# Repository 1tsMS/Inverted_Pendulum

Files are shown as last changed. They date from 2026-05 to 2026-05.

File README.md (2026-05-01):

# 🎯 Inverted Pendulum on Cart (ESP32)

A real-world implementation of the classic inverted pendulum control problem using an ESP32, dual-loop PID control, and a belt-driven linear cart system.

This project demonstrates **nonlinear system stabilization**, **real-time control**, and **embedded implementation of cascade PID control**.

---

## ⚙️ System Overview

The system consists of:

* A **cart moving on a linear rail**
* A **free-rotating pendulum mounted on the cart**
* Real-time feedback using **encoders**
* A **cascade PID controller** to stabilize the pendulum

---

## 🧠 Control Architecture

This project uses a **cascade (dual-loop) PID control system**:

### 🔹 Inner Loop (Fast)

* Controls **pendulum angle**
* Responsible for **balancing**

### 🔹 Outer Loop (Slow)

* Controls **cart position**
* Keeps the cart near the center

```
Position PID → Target Angle → Angle PID → Motor Control
```

---

## 🧰 Hardware Components

### 🔌 Controller

* ESP32 WROOM Development Board

### ⚡ Motor & Drive

* 775 DC Motor (12V, 3000 RPM, dual shaft)
* BTS7960 High Power Motor Driver
* GT2 Belt Drive System
* 16 Teeth Pulley

### 🛤️ Mechanical System

* MGN9H Linear Guide Rail (0.5m)
* Sliding carriage (cart platform)

### 📡 Sensors

#### Pendulum Angle

* 600 PPR Incremental Rotary Encoder
* Mounted directly at the pendulum pivot

#### Cart Position

* AS5600 Magnetic Encoder (I2C)
* Magnet mounted on motor shaft

---

## ⚡ Power System

* 12V, 10A DC Power Supply

---

## 📐 Mechanical Design

* Pendulum:

  * Length: 25 cm
  * Material: Steel rod
  * No additional mass attached

* Drive system:

  * GT2 belt-driven linear motion
  * Compact and lightweight cart design

---

## 🧪 Features

* Real-time encoder feedback
* Multi-turn position tracking using AS5600
* Cascade PID control
* Software safety limits (angle + position)
* Serial-based live PID tuning
* Smooth motor control with filtering

---

## 🧠 Key Concepts Demonstrated

* Inverted pendulum stabilization
* Cascade control systems
* Real-time embedded control (ESP32)
* Encoder signal processing
* Nonlinear dynamics control

---

## 🚀 Getting Started

### 1. Hardware Setup

* Assemble cart on linear rail
* Mount pendulum securely on encoder shaft
* Install GT2 belt and pulley system
* Ensure smooth, low-friction motion

### 2. Wiring

* Connect motor driver to ESP32 GPIO pins
* Connect encoders (quadrature + I2C)
* Ensure **common ground across all components**

---

### 3. Upload Code

* Use Arduino IDE / PlatformIO
* Select ESP32 board
* Upload main control code

---

### 4. Serial Control

| Command | Function |
| --- | --- |
| S | Start system |
| X | Stop system |
| P | Set angle Kp |
| I | Set angle Ki |
| D | Set angle Kd |
| p | Set position Kp |
| d | Set position Kd |

---

## 🎯 PID Tuning Strategy

### Step 1: Tune Angle PID (Inner Loop)

* Disable position control
* Increase Kp until response is fast
* Add Kd to reduce oscillations
* Add small Ki for bias correction

### Step 2: Tune Position PID (Outer Loop)

* Enable position loop
* Start with small Kp
* Add Kd to reduce overshoot

---

## ⚠️ Safety Features

* Automatic motor cutoff if:

  * Pendulum angle exceeds safe limit
  * Cart exceeds track limits

---

## 🔧 Current Status

* Hardware: ✅ Completed
* Encoder feedback: ✅ Working
* PID control: ⚠️ In progress (balancing loop tuned)

---

## 🔮 Future Improvements

* LQR control implementation
* Higher control loop frequency
* Improved motor control using hardware PWM
* Better mechanical damping and rigidity
* Data logging and visualization

---

## 📸 Media

..

---

## 📌 Applications

* Control systems learning
* Robotics and automation education
* Embedded systems development
* Portfolio demonstration project

---

## 🧠 Author Notes

This project focuses on bridging **theory and practical implementation** of control systems. It highlights real-world challenges such as noise, delays, friction, and actuator limitations.

---

## 📜 License

MIT License

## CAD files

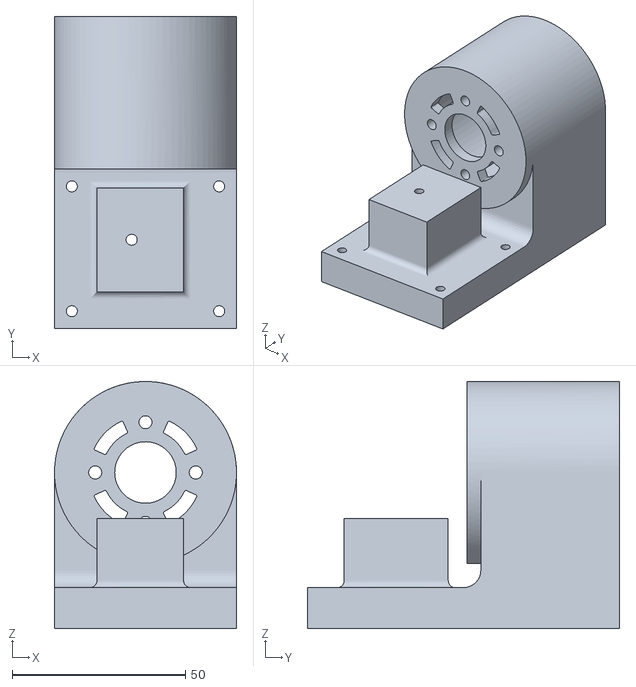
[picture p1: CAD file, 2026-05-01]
3D Models/motor holder.stl
52.5 x 90.0 x 71.2

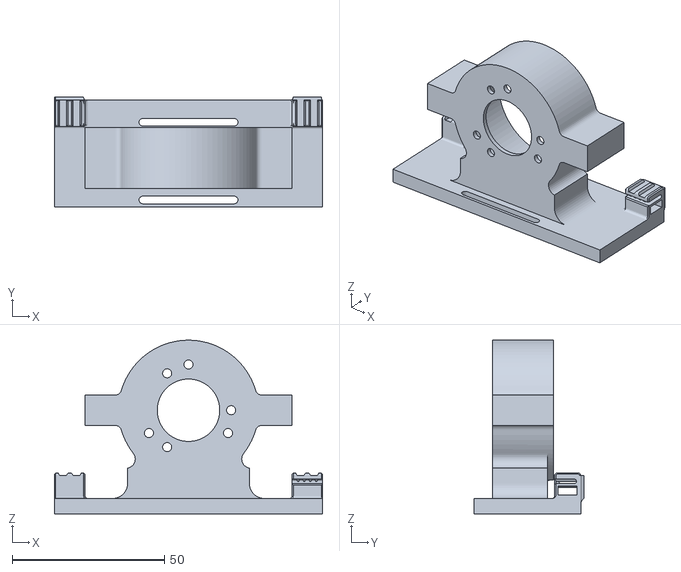
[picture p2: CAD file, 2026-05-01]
3D Models/encoder holderf.stl
88.0 x 36.0 x 57.0

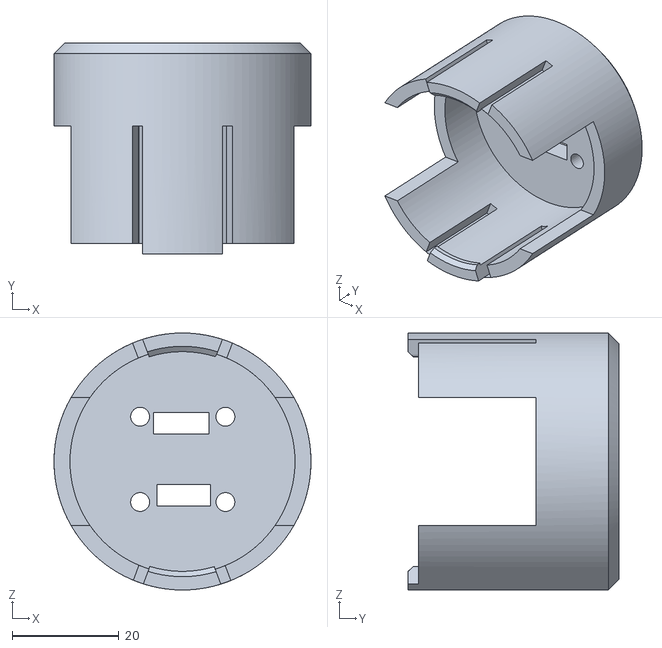
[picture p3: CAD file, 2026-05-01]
3D Models/asholder.stl
48.2 x 39.6 x 48.2

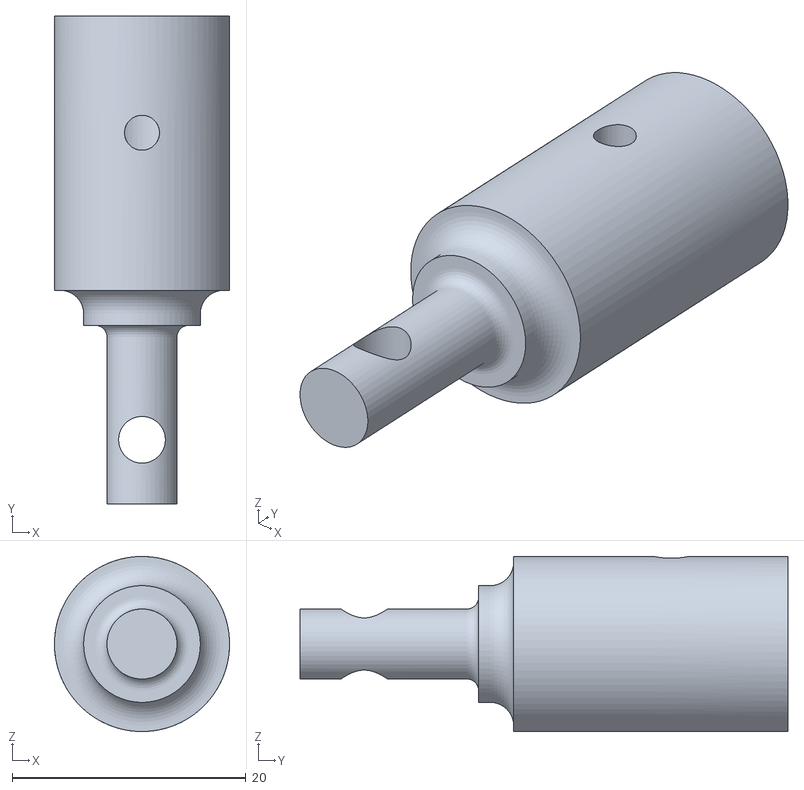
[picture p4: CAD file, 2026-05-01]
3D Models/Pendulum Holder2.stl
15.0 x 41.8 x 15.0

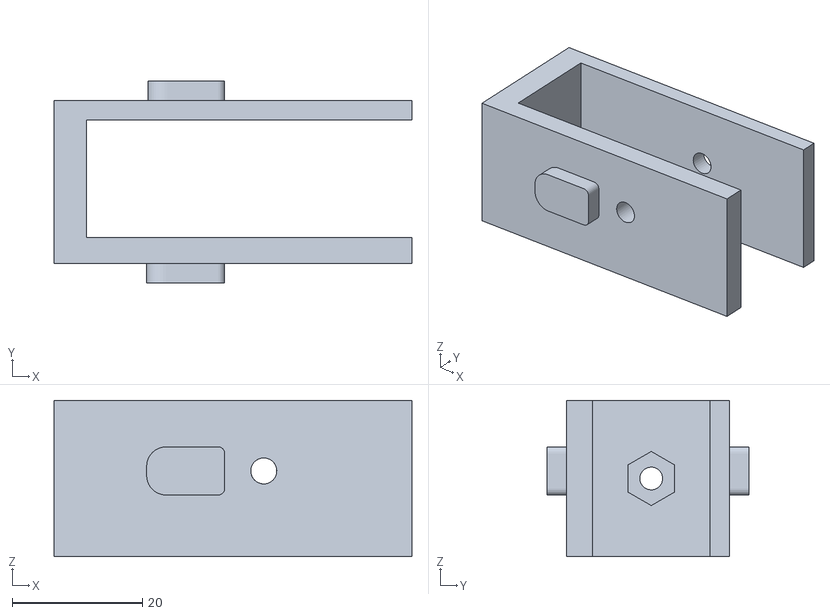
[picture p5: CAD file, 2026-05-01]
3D Models/innerf.stl
55.0 x 31.0 x 24.0

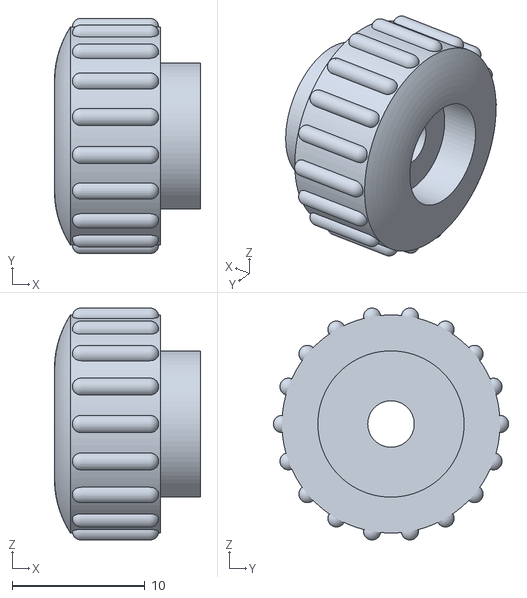
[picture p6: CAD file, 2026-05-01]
3D Models/knob.stl
11.0 x 17.7 x 17.4

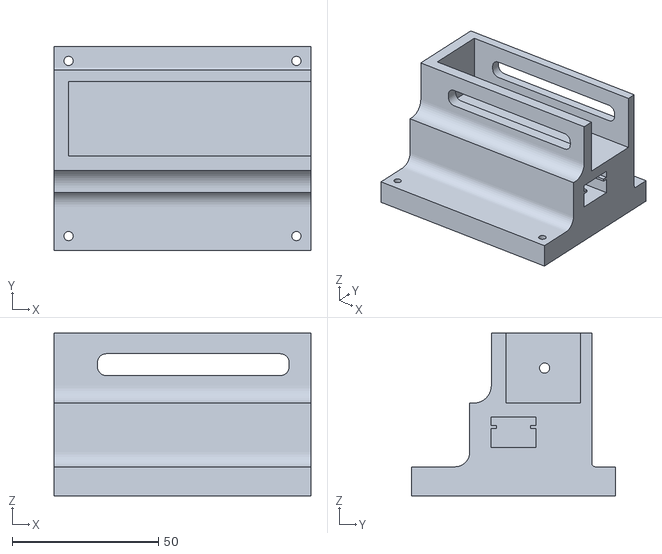
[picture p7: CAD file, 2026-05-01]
3D Models/rail holder 3.stl
88.0 x 70.0 x 55.8

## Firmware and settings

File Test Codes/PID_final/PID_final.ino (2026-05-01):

#include <Arduino.h>
#include <Wire.h>

// --- HARDWARE ---
#define PIN_R_PWM 25
#define PIN_L_PWM 26
#define PIN_EN_R  27
#define PIN_EN_L  14
#define POLE_ENC_A 33
#define POLE_ENC_B 32
#define AS5600_ADDR 0x36
#define RAW_ANGLE_REG 0x0C

// --- CONSTANTS ---
const int PWM_FREQ = 18000;
const int PWM_RES  = 12;
const int PWM_CHANNEL_R = 0;
const int PWM_CHANNEL_L = 1;
const float POLE_PPR = 600.0; // x4 quadrature decoding -> 2400 effective ticks/rev
const float METERS_PER_REV = 0.032;
const float TRACK_LIMIT = 0.10;

// --- PID (TUNED FOR RESPONSE + STABILITY) ---
float Kp_angle = 350.0;
float Ki_angle = 0.0;
float Kd_angle = 120.0;

float Kp_pos = 0.0;
float Ki_pos = 0.0;
float Kd_pos = 0.0;

// --- STATE ---
volatile long poleTicks = 0;

float angleOffset = 0;
int offsetRawAngle = 0;

float currentPos = 0, targetAngle = 0;
float angleErrorI = 0, posErrorI = 0;
float lastAngleError = 0, lastPosError = 0;
float filteredD = 0, smoothPWM = 0;

int lastRawAngle = -1;
long fullRotations = 0;

unsigned long lastTime = 0;
unsigned long lastDebugTime = 0;

bool systemEnabled = false;
bool balanceActive = false;

// --- ENCODER ---
void IRAM_ATTR readPoleA() {
  if (digitalRead(POLE_ENC_A) == digitalRead(POLE_ENC_B)) poleTicks++;
  else poleTicks--;
}

void IRAM_ATTR readPoleB() {
  if (digitalRead(POLE_ENC_A) == digitalRead(POLE_ENC_B)) poleTicks--;
  else poleTicks++;
}

// --- AS5600 ---
uint16_t readAS5600() {
  Wire.beginTransmission(AS5600_ADDR);
  Wire.write(RAW_ANGLE_REG);
  Wire.endTransmission();
  Wire.requestFrom(AS5600_ADDR, 2);
  if (Wire.available() >= 2) return (Wire.read() << 8) | Wire.read();
  return 0;
}

// --- SETUP ---
void setup() {
  Serial.begin(115200);
  Wire.begin(21, 22);
  Wire.setClock(400000);

  ledcSetup(PWM_CHANNEL_R, PWM_FREQ, PWM_RES);
  ledcSetup(PWM_CHANNEL_L, PWM_FREQ, PWM_RES);
  ledcAttachPin(PIN_R_PWM, PWM_CHANNEL_R);
  ledcAttachPin(PIN_L_PWM, PWM_CHANNEL_L);

  pinMode(POLE_ENC_A, INPUT_PULLUP);
  pinMode(POLE_ENC_B, INPUT_PULLUP);
  attachInterrupt(digitalPinToInterrupt(POLE_ENC_A), readPoleA, CHANGE);
  attachInterrupt(digitalPinToInterrupt(POLE_ENC_B), readPoleB, CHANGE);

  pinMode(PIN_EN_R, OUTPUT);
  pinMode(PIN_EN_L, OUTPUT);
  digitalWrite(PIN_EN_R, LOW);
  digitalWrite(PIN_EN_L, LOW);

  lastRawAngle = readAS5600();

  Serial.println("READY: Press S to zero & start");
}

// --- LOOP ---
void loop() {

  // --- COMMANDS ---
  if (Serial.available()) {
    char cmd = Serial.read();

    if (cmd == 'S' || cmd == 's') {

      angleErrorI = 0;
      posErrorI = 0;

      long tickSum = 0;
      for (int i = 0; i < 50; i++) {
        tickSum += poleTicks;
        delay(2);
      }
      angleOffset = -(tickSum / 50.0) * 360.0 / (POLE_PPR * 4.0);

      int raw = readAS5600();
      offsetRawAngle = raw;
      fullRotations = 0;
      lastRawAngle = raw;

      smoothPWM = 0;
      filteredD = 0;
      lastAngleError = 0;
      lastPosError = 0;

      systemEnabled = true;
      balanceActive = false;

      Serial.println("ZERO SET: ANGLE + POSITION");
    }

    if (cmd == 'X' || cmd == 'x') {
      systemEnabled = false;
      stopMotor();
      Serial.println("STOP");
    }
  }

  // --- TIMING ---
  unsigned long now = micros();
  float dt = (now - lastTime) / 1e6;
  if (dt < 0.004) return;

  // --- ANGLE ---
  float rawAngle = -(poleTicks * 360.0 / (POLE_PPR * 4.0));
  float currentAngle = rawAngle - angleOffset;
  // --- POSITION ---
  int raw = readAS5600();
  if (lastRawAngle != -1) {
    int diff = raw - lastRawAngle;
    if (diff < -2048) fullRotations++;
    else if (diff > 2048) fullRotations--;
  }
  lastRawAngle = raw;

  float absolutePos = ((fullRotations * 4096.0 + raw) / 4096.0) * METERS_PER_REV;
  float zeroPos = (offsetRawAngle / 4096.0) * METERS_PER_REV;
  currentPos = -(absolutePos - zeroPos);
  // --- OUTER PID ---
  float posError = -currentPos;
  //if (abs(posError) < 0.02) posError *= 0.3;
  posErrorI = constrain(posErrorI + posError * dt, -0.2, 0.2);
  float posD = (posError - lastPosError) / dt;
  targetAngle = Kp_pos * posError + Ki_pos * posErrorI + Kd_pos * posD;
  targetAngle = constrain(targetAngle, -6.0, 6.0);

  // --- INNER PID ---
  float angleError = targetAngle - currentAngle;
  if (abs(angleError) < 1.0) angleError *= 0.5;
  angleErrorI = constrain(angleErrorI + angleError * dt, -10, 10);

  float rawD = (angleError - lastAngleError) / dt;
  filteredD = 0.45 * rawD + 0.55 * filteredD;

  float output = Kp_angle * angleError + Ki_angle * angleErrorI + Kd_angle * filteredD;

  // --- CONTROL ---
  if (systemEnabled) {

    if (!balanceActive && abs(currentAngle) < 10.0) {
      balanceActive = true;
      digitalWrite(PIN_EN_R, HIGH);
      digitalWrite(PIN_EN_L, HIGH);
    }

    if (balanceActive && abs(currentAngle) < 45 && abs(currentPos) < TRACK_LIMIT) {
      driveMotor(constrain(output, -4095, 4095));
    } else {
      stopMotor();
    }
  }

  // --- DEBUG OUTPUT ---
  if (millis() - lastDebugTime > 50) {

    
    Serial.print("Angle:"); Serial.print(currentAngle, 2); Serial.print("\t");
    Serial.print("Target:"); Serial.print(targetAngle, 2); Serial.print("\t");
    Serial.print("Pos_mm:"); Serial.print(currentPos * 1000.0, 1); Serial.print("\t");
    Serial.print("PWM:"); Serial.print(smoothPWM, 0); Serial.print("\t");
    Serial.print("Output:"); Serial.print(output, 2);
    Serial.println();

    lastDebugTime = millis();
  }

  lastAngleError = angleError;
  lastPosError = posError;
  lastTime = now;
}

// --- MOTOR ---
void driveMotor(int speed) {

  if (speed > 0 && speed < 40) speed = 40;
  else if (speed < 0 && speed > -40) speed = -40;
  else if (speed == 0) speed = 0;

  smoothPWM = 0.85 * speed + 0.15 * smoothPWM;
  static float lastPWM = 0;
  float maxStep = 400;  // tune this (200–500 range)

  float delta = smoothPWM - lastPWM;
  delta = constrain(delta, -maxStep, maxStep);

  smoothPWM = lastPWM + delta;
  lastPWM = smoothPWM;
  int pwm = constrain((int)smoothPWM, -4095, 4095);

  if (pwm > 0) {
    ledcWrite(PWM_CHANNEL_R, pwm);
    ledcWrite(PWM_CHANNEL_L, 0);
  } else if (pwm < 0) {
    ledcWrite(PWM_CHANNEL_R, 0);
    ledcWrite(PWM_CHANNEL_L, -pwm);
  } else {
    ledcWrite(PWM_CHANNEL_R, 0);
    ledcWrite(PWM_CHANNEL_L, 0);
  }
}

// --- STOP ---
void stopMotor() {
  digitalWrite(PIN_EN_R, LOW);
  digitalWrite(PIN_EN_L, LOW);
  ledcWrite(PWM_CHANNEL_R, 0);
  ledcWrite(PWM_CHANNEL_L, 0);

  smoothPWM = 0;
  angleErrorI = 0;
  posErrorI = 0;
  balanceActive = false;
}

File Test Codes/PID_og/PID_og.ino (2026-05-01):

/* * ======================================================================================
 * PROJECT: FINAL ROBUST MICRO-PENDULUM (BTS7960) - I2C AS5600 VERSION
 * CONFIG: Pole (600PPR Optical) | Cart (AS5600 I2C Mode)
 * PINS: SDA(21), SCL(22) for AS5600 | R_PWM(25), L_PWM(26), R_EN(27), L_EN(14)
 * ======================================================================================
 */

#include <Arduino.h>
#include <Wire.h>

// --- BTS7960 PINS ---
#define PIN_R_PWM 25 
#define PIN_L_PWM 26
#define PIN_EN_R  27 
#define PIN_EN_L  14 

// --- POLE ENCODER PINS ---
#define POLE_ENC_A 33  
#define POLE_ENC_B 32  

// --- AS5600 I2C CONFIG ---
#define AS5600_ADDR 0x36
#define RAW_ANGLE_REG 0x0C

// --- PHYSICAL CONSTANTS ---
const float POLE_PPR = 600.0;           
const int   PULLEY_TEETH = 16;          
const float BELT_PITCH = 0.002;         
const float METERS_PER_REV = PULLEY_TEETH * BELT_PITCH;
const float TRACK_LIMIT = 0.06; 

// --- PID VARIABLES ---
float Kp_angle = 68.0, Ki_angle = 0.25, Kd_angle = 2.8;
float Kp_pos   = 0.10, Ki_pos   = 0.0,  Kd_pos   = 0.04;

// --- STATE VARIABLES ---
volatile long poleTicks = 0;
float currentPos = 0, lastPos = 0;
float targetAngle = 0, smoothPWM = 0;
float angleErrorI = 0, posErrorI = 0;
float lastAngleError = 0, lastPosError = 0;

// AS5600 Multi-turn tracking
int lastRawAngle = -1;
long fullRotations = 0;

unsigned long lastTime = 0, lastDebugTime = 0;
bool systemEnabled = false; 
bool balanceActive = false; 

// --- POLE INTERRUPT ---
void IRAM_ATTR readPole() { if (digitalRead(POLE_ENC_A) == digitalRead(POLE_ENC_B)) poleTicks++; else poleTicks--; }

// --- AS5600 I2C READER ---
uint16_t readAS5600() {
  Wire.beginTransmission(AS5600_ADDR);
  Wire.write(RAW_ANGLE_REG);
  Wire.endTransmission();
  Wire.requestFrom(AS5600_ADDR, 2);
  if (Wire.available() >= 2) {
    uint16_t highByte = Wire.read();
    uint16_t lowByte = Wire.read();
    return (highByte << 8) | lowByte;
  }
  return 0;
}

void setup() {
  Serial.begin(115200);
  Wire.begin(21, 22); // SDA, SCL pins for ESP32
  
  pinMode(POLE_ENC_A, INPUT_PULLUP); pinMode(POLE_ENC_B, INPUT_PULLUP);
  attachInterrupt(digitalPinToInterrupt(POLE_ENC_A), readPole, RISING);
  
  pinMode(PIN_R_PWM, OUTPUT); pinMode(PIN_L_PWM, OUTPUT); 
  pinMode(PIN_EN_R, OUTPUT);  pinMode(PIN_EN_L, OUTPUT);
  digitalWrite(PIN_EN_R, LOW); digitalWrite(PIN_EN_L, LOW);

  // Initialize AS5600 baseline
  lastRawAngle = readAS5600();

  Serial.println("\n--- I2C MICRO-PENDULUM READY ---");
  Serial.println("S = Start | X = Stop | P/I/D/p/d = Tune");
}

void loop() {
  // --- SERIAL COMMAND PARSER ---
  if (Serial.available() > 0) {
    char cmd = Serial.read();
    if (cmd == 'S' || cmd == 's') { systemEnabled = true; Serial.println(">>> ARMED"); } 
    else if (cmd == 'X' || cmd == 'x') { systemEnabled = false; stopMotor(); Serial.println("!!! KILLED"); } 
    else {
      float val = Serial.parseFloat();
      switch (cmd) {
        case 'P': Kp_angle = val; break;
        case 'I': Ki_angle = val; break;
        case 'D': Kd_angle = val; break;
        case 'p': Kp_pos = val; break;
        case 'd': Kd_pos = val; break;
      }
    }
  }

  unsigned long currentTime = millis();
  float dt = (currentTime - lastTime) / 1000.0;
  if (dt < 0.01) return; // 100Hz Loop

  // 1. UNIT CONVERSION & AS5600 UNWRAPPING
  float currentAngle = -(poleTicks * 360.0 / POLE_PPR); 
  
  int rawAngle = readAS5600();
  // Detect full rotation jump (4096 to 0 or 0 to 4096)
  if (lastRawAngle != -1) {
    int diff = rawAngle - lastRawAngle;
    if (diff < -2048) fullRotations++;      // Clockwise wrap
    else if (diff > 2048) fullRotations--;   // Counter-clockwise wrap
  }
  lastRawAngle = rawAngle;
  
  long totalTicks = (fullRotations * 4096) + rawAngle;
  currentPos = (totalTicks / 4096.0) * METERS_PER_REV;

  // 2. OUTER LOOP (POSITION)
  float posError = 0.0 - currentPos; 
  posErrorI = constrain(posErrorI + (posError * dt), -0.5, 0.5);
  float posDeriv = (posError - lastPosError) / dt;
  targetAngle = (posError * Kp_pos) + (posErrorI * Ki_pos) + (posDeriv * Kd_pos);
  targetAngle = constrain(targetAngle, -10, 10); 

  // 3. INNER LOOP (BALANCE)
  float angleError = targetAngle - currentAngle;
  if (abs(angleError) < 0.05) angleError = 0; 
  angleErrorI = constrain(angleErrorI + (angleError * dt), -35, 35);
  float angleDeriv = (angleError - lastAngleError) / dt;
  float motorOutput = (angleError * Kp_angle) + (angleErrorI * Ki_angle) + (angleDeriv * Kd_angle);

  // 4. SAFETY & CONTROL
  if (systemEnabled) {
    if (!balanceActive && abs(currentAngle) < 2.0) {
      balanceActive = true;
      digitalWrite(PIN_EN_R, HIGH); digitalWrite(PIN_EN_L, HIGH);
    }
    if (balanceActive && abs(currentAngle) < 32.0 && abs(currentPos) < TRACK_LIMIT) {
      driveBTS7960(constrain(motorOutput, -255, 255));
    } else if (balanceActive) {
      stopMotor(); 
    }
  }

  // 5. DEBUGGING (10Hz)
  if (currentTime - lastDebugTime > 100) {
    if (systemEnabled) {
      Serial.print("A:"); Serial.print(currentAngle, 1);
      Serial.print(" P_mm:"); Serial.print(currentPos * 1000.0, 1);
      Serial.print(" T:"); Serial.print(targetAngle, 1);
      Serial.print(" O:"); Serial.println(smoothPWM, 0);
    }
    lastDebugTime = currentTime;
  }

  lastAngleError = angleError; lastPosError = posError; lastTime = currentTime;
}

void driveBTS7960(int speed) {
  if (abs(speed) > 1) speed += (speed > 0) ? 40 : -40; 
  smoothPWM = (0.45 * speed) + (0.55 * smoothPWM);    
  int finalPWM = constrain((int)smoothPWM, -255, 255);
  if (finalPWM > 0) { analogWrite(PIN_R_PWM, finalPWM); analogWrite(PIN_L_PWM, 0); }
  else { analogWrite(PIN_R_PWM, 0); analogWrite(PIN_L_PWM, abs(finalPWM)); }
}

void stopMotor() {
  digitalWrite(PIN_EN_R, LOW); digitalWrite(PIN_EN_L, LOW);
  analogWrite(PIN_R_PWM, 0); analogWrite(PIN_L_PWM, 0);
  balanceActive = false; smoothPWM = 0; angleErrorI = 0; posErrorI = 0;
}
